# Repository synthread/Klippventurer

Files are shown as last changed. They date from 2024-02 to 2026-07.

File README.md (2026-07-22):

<div align="center">
  Klippventurer logo
  <h1>Klippventurer</h1>
  <h3>Klipperize your FlashForge printer!</h3>
  <a href="https://discord.gg/ns2pFdhdMW">
    
    
  </a>
</div>

<div align="center">
  <a href="#compatibility">Compatibility</a> •
  <a href="#installation">Installation</a> •
  <a href="#known-issues">Known Issues</a> •
  <a href="docs/changelog.md">Changelog</a> •
  <a href="#special-thanks">Special Thanks</a>
</div>

> [!IMPORTANT]
> `main` documents the current live Klippventurer setup: a **v0.2.x manual/soldered host install** workflow (ongoing state, not a tagged release line).
> Looking for the next-generation stock-like USB installer work? See the preview **USB Install Branch**: [`next/firmware-package`](https://gitlab.com/synthread/proj/Klippventurer/-/tree/next/firmware-package).
> That branch is preview-only and is not merged to `main` until a verified USB installer exists.

## Compatibility

|Printer|Printing|Easy Installer|Pin table|Printer.cfg|Thermistor Calibration|Display|Touch|Filament Runout|Camera|
|---|---|---|---|---|---|---|---|---|---|
|Adventurer 3/Pro*|✅|⏰|✅|✅|⏰|⏰|⏰|⏰|⏰|
|Adventurer 3 Pro 2|❓|⏰|❓|❓|⏰|⚠️|⚠️|⚠️|⚠️|
|Adventurer 4|⚠️|⏰|⚠️|⚠️|⏰|⚠️|⚠️|⚠️|⚠️|
|Adventurer 5M/Pro|✅|⚠️|✅|✅|✅|✅|✅|✅|✅|
|Creator Pro 2|⚠️|⚠️|❓|⚠️|⚠️|⚠️|⚠️|❌|❌|
|Creator 3/Pro |⚠️|⏰|⚠️|⚠️|⚠️|⚠️|⚠️|❌|❌|

✅Working ⠀⠀ ⏰In Progress ⠀⠀ ⚠️Not yet Working ⠀⠀ ❌Not planned or lacks hardware feature ⠀⠀ ❓Untested, might work

> [!NOTE]
> "Adventurer 3" Includes the Adventurer 3C, Lite, and Pro, as well as rebrands such as the Bresser Rex, Arçelik PT1000, MonoPrice Voxel, and potentially other printers based on the SZ16 mainboard.

## Installation
For installation instructions, please see [the docs](docs/installation.md)

> [!WARNING]
> Always calibrate your Z offset and mesh bed leveling after installing Klipper!

This repo, supported features, and guides change often, join our [Discord](https://discord.gg/ns2pFdhdMW) or watch the repo for updates.
Please open an issue or pull request if you encounter any problems with installation.

## Known Issues 
### Adventurer 3 Models
- Nation N32G MCU doesn't work with current .config
- Can't currently support screen, buzzer, USB, filament runout sensor, or camera. Support for these is planned as part of future USB installer work.
- Adventurer 3 Pro works, but you need to modify printer.cfg to use TMC2209 drivers instead of TMC2208.

## Special Thanks
[@hw-lunemann](https://github.com/hw-lunemann) for fixing UART muxing and tuning input shaper on Adventurer 3

[@kyleisah](https://github.com/kyleisah) and everyone who contributed to [KAMP](https://github.com/kyleisah/Klipper-Adaptive-Meshing-Purging)

[@KevinOConnor](https://github.com/KevinOConnor) and everyone who contributed to [Klipper](https://github.com/Klipper3d/klipper)

[@FlashforgeOfficial](https://github.com/FlashforgeOfficial) for good hardware at a fair price

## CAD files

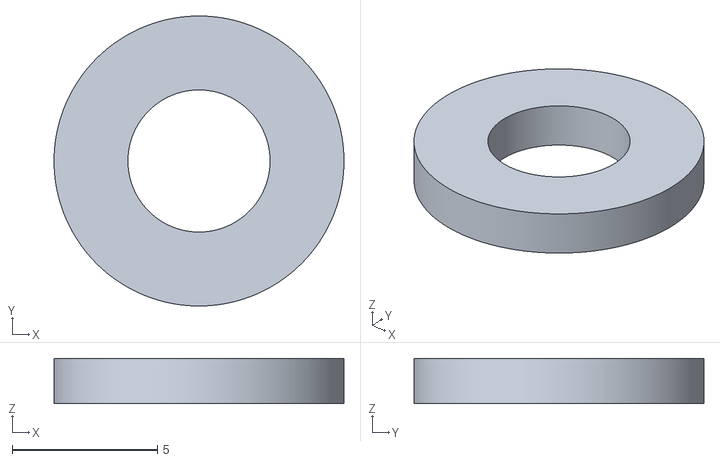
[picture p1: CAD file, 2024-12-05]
STLs/Adv3 Extruder Spacer.stl
10.00 x 10.00 x 1.56

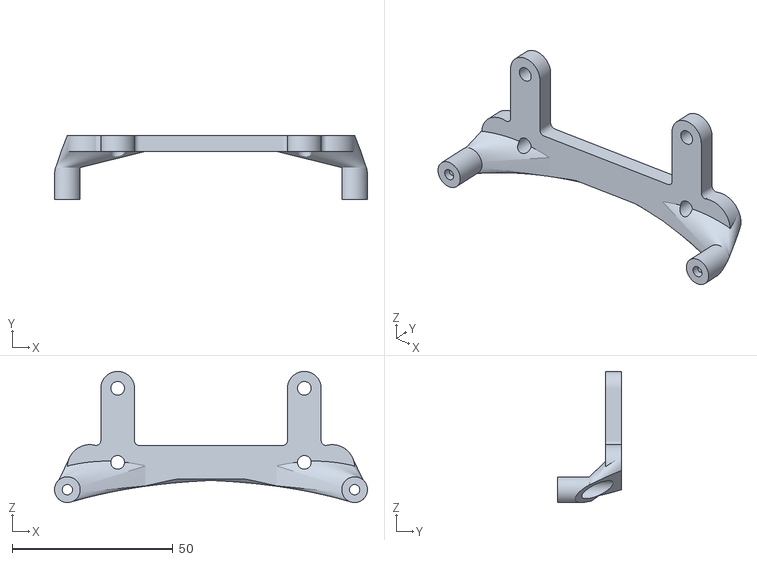
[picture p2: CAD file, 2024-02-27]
STLs/Adv3 Pi Zero mount.stl
97.2 x 20.0 x 40.7

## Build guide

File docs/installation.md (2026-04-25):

# Installation ADV3

> [!CAUTION]
> You should be familiar with installing and configuring Klipper before attempting this.
> You are solely responsible for any damage caused by following any part of this guide.

> [!WARNING]
> This guide will soon be deprecated as this install method is considered to be in an ALPHA testing state.
> Public testing for the BETA install method will be beginning soon, join our Discord to keep up to date with announcements.

> [!WARNING]
> CHECK your microcontroller brand before attempting this. It will only work on STM32, HK32, and GD32 MCUs.
> Nation N32 MCUs are not supported by this guide as they need to be programmed via a slightly different method.

> [!NOTE]
> This Guide was written with [Raspberry Pi Imager v2.0.2](https://github.com/raspberrypi/rpi-imager/releases/tag/v2.0.2) and Raspbian GNU/Linux 12 (bookworm) armv7l on a [Raspberry Pi Zero 2 W Rev 1.0](https://www.raspberrypi.com/products/raspberry-pi-zero-2-w/) with Linux 6.12.47+rpt-rpi-v7

## Requirements

+ very basic soldering skills
+ a soldering iron with temperature control
+ solder (preferably SnPb or SnBi solder, SnAg is harder to work with)
+ A [Raspberry Pi Zero 2 W](https://www.raspberrypi.com/products/raspberry-pi-zero-2-w/) (or any other Pi you'll just need to select it in the Raspberry Pi Imager)
+ SD card (at least 4GB, 16GB or larger recommended)
+ insulated silicone wire, multiple colors preferred (silicone insulation won't melt during soldering)
+ 4x M2.5x4 screws
+ 4x M2.5 threaded heat-set inserts
+ Raspberry Pi Zero mount from the [STLs](/STLs/) folder

### Recommended

+ Extruder tensioning spacer from the [STLs](/STLs/) folder
+ paste or liquid flux
+ cotton swabs and or cotton pads (something to clean the board with)
+ IPA or PCB cleaner

## Part 1 - Get Connected 🔌

> [!IMPORTANT]
> Don't work inside the printer with the power cable connected

Step 1: Print the Pi mount and (optional) extruder spacer from the [STLs](/STLs/) folder. The Pi mount is designed to be printable on Adventurer 3 without support material. PLA may not work due to the temperature of the electronics enclosure, HTPLA or higher glass transition filament (PETG, ABS, etc.) recommended.
Insert the 4 threaded inserts into the Pi mount using your soldering iron with a conical tip or threaded insert tip.

Optional Step: With the printer unplugged, use a hex 2.5 bit or Allen key to remove the tensioning arm from the extruder assembly behind the filament hatch. Be careful not to drop the spring into the housing of the printer, it's much less work if you don't have to fish the spring out. Install the spacer onto the spring retention peg. Reassemble the extruder. Video demonstration here: https://www.youtube.com/shorts/PZRefwOkk9g
This will improve the maximum flow rate significantly, and coupled with the increased extruder motor torque in Klipper, massively reduces or eliminates the clicking extruder issue.

Step 2: Unplug your printer. Carefully turn the printer upside down on a soft surface so as to not scratch the top acrylic panel.
Remove the 4 screws securing the metal electronics cover.
You may choose to remove the board from the printer and place it on your work surface to make soldering easier.
If you do, you'll need to remove the glue covering the MHF micro-coax Wi-Fi antenna cable, unplug all connectors, and remove all 4 screws securing the board.

Step 3: Locate the pads in the diagram ([Wiring-diagram.png](../images/adv3-diagram.png)), apply flux, then tin the pads.

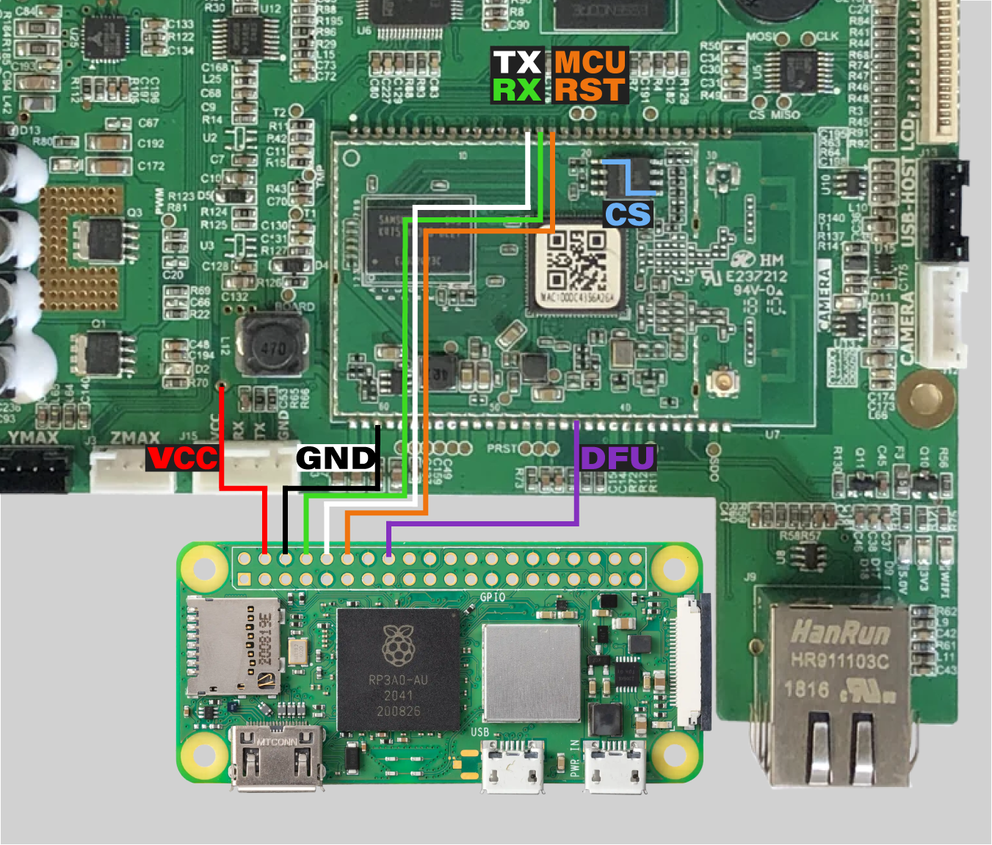
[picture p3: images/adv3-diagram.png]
wiring diagram


Step 4: Solder your wires to the pads as indicated. Make sure all wires are long enough to connect to your Pi, about 10cm or 4in. Strip both ends before soldering to make your life easier later (about 2mm on each end)
You should connect the following to your printer's mainboard:
+ one wire to TX (white)
+ one wire to RX (green)
+ one wire to MCU RST (orange)
+ one wire to DFU (purple)
+ one wire to VCC (red)
+ one wire to GND (black)
+ bridge CS (blue)

## Part 2 - Prepare The Pi 🪛

Step 1: Download the latest [Raspberry Pi Imager](https://www.raspberrypi.com/software/) Under "Raspberry Pi Device" select "Raspberry Pi Zero 2 W" (or your Pi). For Operating System, go to "Raspberry Pi OS (other)" and select "Raspberry Pi OS (Legacy, 32-bit) Lite", choose your SD card, then hit next. Complete Customisation (like selecting your hostname). Under "Remote Access" enable SSH and select "Use password authentication" (unless you know what you're doing). Save, then click "Write" and "I UNDERSTAND, ERASE AND WRITE" when it asks if you're sure you want to continue. Once done writing the SD, remove it and insert it into the Pi.

Step 2: If you removed the mainboard to solder your wires, reinstall it now, but leave out the 2 screws closest to the power socket. If you left the board in, go ahead and remove those 2 screws now. Place your Pi mounting bracket on the mainboard with the two legs aligned with the holes in the mainboard. Insert the two mainboard screws through the bracket and mainboard to secure them both. Using the 4 M2.5 screws, secure the Pi to the mounting bracket.

Step 3: Time to test! Plug the printer back into power, and flip the switch on. The printer **should not** boot up. Screen should remain black, mainboard LEDs should come on, the Pi should power up, and nothing else should happen. If the printer does boot normally into the stock firmware, make sure the CS bridge is in place and works. If all works, now is the time to clean the flux off the board with your cleaner and cotton swabs.

## Part 3 - Klipper, Mainsail, Fluidd, Orca Slicer! ⛵💧🐋

Step 1: SSH into your Pi. You'll need to find the IP in your router's config page or app.

Run the following commands:

```sh
echo -e "enable_uart=1\ndtoverlay=miniuart-bt\ndtoverlay=disable-bt" | sudo tee -a /boot/firmware/config.txt
sudo sed -i 's/console=serial0,115200 //' /boot/firmware/cmdline.txt
sudo apt update && sudo apt install stm32flash git -y
cd ~ && git clone https://github.com/dw-0/kiauh.git
git clone https://gitlab.com/synthread/3d/Klippventurer.git
./kiauh/kiauh.sh
```

Once at the KIAUH menu, install 1) Klipper, 2) Moonraker, and 4) Fluidd. You can also install Mobileraker (under Extensions) for mobile push notifications via the [Mobileraker app](https://mobileraker.com/).
Exit KIAUH with B then Q and do

```sh
cp -r ~/Klippventurer/config/ ~/printer_data/
wget -O ~/klipper/.config https://gitlab.com/synthread/3d/Klippventurer-Installer/-/raw/main/configs/adventurer3.config
cd ~/klipper && make menuconfig
```

press Q followed by Y. Now

```sh
make
```

and if the build completes without errors,

```sh
sudo reboot
```

Wait for the Pi to reboot, SSH back in and run

```sh
sudo stm32flash -w ~/klipper/out/klipper.bin -R -i -530,535,530:-530,-535,530 /dev/ttyAMA0
```

A successful flash should look something like this:

```sh
stm32flash 0.7

http://stm32flash.sourceforge.net/

Using Parser : Raw BINARY
Size         : 38368
Interface serial_posix: 57600 8E1

GPIO sequence start
 setting gpio 530 to 0... OK
 delay 100000 us
 setting gpio 535 to 1... OK
 delay 100000 us
 setting gpio 530 to 1... OK
GPIO sequence end

Version      : 0x10
Option 1     : 0x00
Option 2     : 0x00
Device ID    : 0x0414 (STM32F10xxx High-density)
- RAM        : Up to 64KiB  (512b reserved by bootloader)
- Flash      : Up to 512KiB (size first sector: 2x2048)
- Option RAM : 16b
- System RAM : 2KiB
Write to memory
Erasing memory
Wrote address 0x080095e0 (100.00%) Done.

Resetting device...

GPIO sequence start
 setting gpio 530 to 0... OK
 delay 100000 us
 setting gpio 535 to 0... OK
 delay 100000 us
 setting gpio 530 to 1... OK
GPIO sequence end

Reset done.
```

You should now be able to access the Fluidd interface from your browser or Orca Slicer. If you don't get an error (warnings are fine), go ahead and unplug the printer and reinstall the bottom cover. You may need to try restarting the firmware.

Set it back right-side-up and power it on. Reconnect to Fluidd, cross your fingers, and hit the home button!

Calibrate your Z offset and make a bed mesh and also probably an [PID calibration](https://www.klipper3d.org/Config_checks.html#calibrate-pid-settings)!

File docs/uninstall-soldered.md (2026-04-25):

# Uninstall (soldered)

Reverting your printer to stock firmware is easy. Simply remove your wires from the mainboard, remove the Pi mount, and power on the printer. After a short wait on the splash screen, you should be greeted by a prompt asking if you want to retry the "update". This will reinstall the factory firmware on the microcontroller. Follow the on-screen prompts and your printer should be back to stock in no time. If this is unsuccessful, don't worry, and continue on to the troubleshooting section below.

## Troubleshooting
Sometimes, this built-in recovery mechanism can fail to reinstall the original firmware. In this case, you will need to reinstall the firmware manually. Thankfully, this is easy to do and only requires a USB flash drive. Steps are as follows: 

0) Download the latest firmware for your printer from the manufacturer's website. For the FlashForge branded Adventurer 3, it can be found [here.](https://archive.org/details/adv-3-firmware) For rebrands, you can likely find your firmware on the seller's website by Googling "\<printer name> firmware" or you can try using the official firmware from FlashForge. Some models such as the MonoPrice Voxel can unlock additional features by using official firmware instead of firmware from the printer's distributor.

> [!CAUTION]
> Do not use a flash drive containing any important files, you will need to erase this drive.

1) Insert your USB flash drive into your PC.
2) Flash your drive to FAT32:
    - (Windows) Use [GUIFormat](http://ridgecrop.co.uk/index.htm?guiformat.htm) to format your flash drive as FAT32
    - (Linux) Use your tool of choice to format your flash drive as FAT32
    - (macOS) Open Disk Utility. Select your flash drive on the left, then "Erase". Choose "MS-DOS (FAT32)" from the dropdown, then click the "Erase" button.
3) Extract the firmware .zip file. Open the folder within to find your firmware name e.g. Adventurer3-*.tgz Move this file onto your empty flash drive, and eject it from the computer.
4) With the printer powered off, insert your USB flash drive. Power on the printer.
5) You should see a firmware update begin after the splash screen. Once this is completed, you may remove the flash drive and restart the printer. You should now be back to factory firmware!

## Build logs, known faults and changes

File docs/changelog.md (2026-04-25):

# Changelog

This changelog tracks user-facing changes to the current live Klippventurer project line.

## v0.2.2 - Upcoming

### Changed

- Clarifies that `main` is the current live v0.2.x manual/soldered host install workflow.
- Links from the README to the preview **USB Install Branch** (`next/firmware-package`) for next-generation stock-like USB installer work.
- Centers the README navigation links under the Discord badge for GitLab rendering.
- Updates the Adventurer 3 installation guide for Raspberry Pi Imager 2.0.2 and Raspberry Pi OS Bookworm paths.
- Updates setup commands to use GitLab-hosted Klippventurer URLs.
- Temporarily keeps KAMP setup out of the manual installation flow pending Discord context and a proper fix for the issue that prompted its removal.
- Updates STM32 flashing instructions and includes an example successful `stm32flash` output.
- Adds clearer post-install calibration guidance.
- Updates the soldered-install recovery firmware link.

### Notes

- This remains the manual/soldered host install project line.
- N32 MCU support and the stock-like USB installer are not included in v0.2.2; those are being developed on the preview USB installer branch.

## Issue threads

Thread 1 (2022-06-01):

Support stock mainboard

VioSynthax, 2022-06-01:
Stock mainboard can be supported by running Klipper, Mainsail, and Fluidd off of the original Mediatek MT7688 running a somewhat modified OpenWrt installation. This requires a good understanding of Linux. This could be done in one of three ways.

Method 1 [best method]) Create a USB installer that updates the kernel to the latest (older FlashForge kernel can't run Klipper) and installs KlipperWrt while disabling all of the FlashForge start scripts except the updater script, so that any update USB can revert the printer to stock. Flash the MCU and print away. (best method)

Method 2 [2nd best]) Connect to the MT7688 via serial UART and manually disable FlashForge's start scripts after updating to the latest firmware. Fix the OpenWrt installation and add KlipperWrt's distfeeds. Install KlipperWrt manually, then flash the MCU.

Method 3 [not recommended]) Gain SSH access via CrashForge, then manually install everything the same way as method 2. Harder to unbrick than method 2.

dJOS1475, 2022-06-01:
Howdy, I'd love to change my AD3 over to Klipper (I currently run it on my main printer SKR2 powered and heavily modified Mega Zero v1.0).

Method 1 would be ideal - how close are we to being able to do this?

dJOS1475, 2022-06-01:
Awesome, if you'd like me to test I'm happy to help out. I dont mind risking my unit as it's my "backup" printer and if it goes very badly wrong I'll just have to replace the main board with a Mellow Fly. 🤣

VioSynthax, 2022-06-01:
> Awesome, if you'd like me to test I'm happy to help out. I dont mind risking my unit as it's my "backup" printer and if it goes very badly wrong I'll just have to replace the main board with a Mellow Fly. 🤣

I originally was just going to throw in a new board entirely but felt bad at wasting good TMC2209s 😋

dJOS1475, 2022-06-01:
PS. I was planning to make an adapter PCB board to allow the easy swap in of a RepRap Fly board - unfortunately I just havent had the time to map out the FlatFlex pinouts etc

VioSynthax, 2022-06-04:
> PS. I was planning to make an adapter PCB board to allow the easy swap in of a RepRap Fly board - unfortunately I just havent had the time to map out the FlatFlex pinouts etc

I've mostly mapped out the flex, but not entirely. I didn't spend enough time on it to figure out how the LED is connected, but now that I have it running Klipper it'd be easy enough to just enable things one-by-one and measure which pin has voltage. I think making some adapter boards and firmware mods for these printers would really breathe a lot of life into quite a few machines that would otherwise become e-waste.

dJOS1475, 2022-06-04:
Agreed, mine just doesn’t get used ATM due to the horribly inaccurate bed leveling. I’m hoping Klipper will solve that issue as the “paper test” in Klipper had much more precise z axis control than the Flashforge firmware.

Btw I bought a PEI spring steel bed for it mine which would be awesome for printing ABS+ if I could get the bed mesh sorted.

https://a.aliexpress.com/_mM14t4W

VioSynthax, 2022-06-04:
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

Yeah, without a probe it's still not as good as I'd like it, but maybe that's just me. My theory is that it's somewhat due to backlash, but I believe Klipper's manual leveling "bounces" between moves to prevent inaccuracies caused by backlash. I got mine pretty good and then edited the mesh by hand doing a few first layer tests until it was nearly perfect across the entire bed.
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

dJOS1475, 2022-06-05:
Wow, that’s massively better than what I’ve been getting out of mine!

Borillion, 2022-11-14:
Sorry to bump this if its necro/abandoned. I have one of these that I was able to get SSH access into using a reverse shell, by pulling and modding the scripts off of a usb firmware update.

I assume I have to start by pulling the device tree and kernel configuration off after updating to the newest firmware.

Not too familiar with building openwrt willing to give it a good try but will need someone to discuss the process with.

When printing it seems to write to some /sys/kernel/ pinctrl devices. So far i'm just poking dangerously and playing with strace/ptrace and the qtlib qui.

VioSynthax, 2023-01-09:
> I have got a [Arçelik PT1000](https://www.arcelik.com.tr/3d-yazici/arcelik-3d-yazici-pt1000-3d-yazici) last week thinking that it is another rebrand of the Adventurer 3 but suprisingly enough it has some differences like a newer revision of the main board and a different heat plate (looks like Adventurer 4 bed but smaller). Most importantly it has OpenWRT 18.06.4 installed with the 4.14.131 kernel and i cannot install the official firmware because of that. I can share the whole disk image in exchange of a disk image from the official model so i can install the flashforge software and you can try to install the KlipperWRT on 4.14.131 kernel.

Can you share a high resolution clear photo of the mainboard? If the hardware isn't supported by FF's firmware it won't work even if you get it to install. It probably won't install Adventurer firmware because their update mechanism either works differently or checks the update USB before applying it. If you can get Crashforge to run on it, it should be quite easy to force install the Adventurer firmware. Why do you want Flashforge's firmware anyway, does it have features the stock firmware doesn't?

VioSynthax, 2023-01-09:
Probably doesn't have a camera to free up the USB header for the RFID reader. If you want to flash a different kernel, your best bet is to either use a SOIC clip on the NOR flash on the Mediatek board, or flash it by accessing U-boot's boot menu via serial, if the boot menu is enabled on the bootloader they are using.

hw-lunemann, 2024-01-07:
Hey I'm back! Sorry for not getting back to this or updating on my progress.
I have long given up on getting klipper to run on the embedded mediatek board and haven't really worked on it anymore either. It simply doesn't have enough ram to make it fit. That would definitely been nice though but even if it did fit, the CPU is also very slow and could have supported tectnoically slow printing speeds.

Good news is that I started work on figuring out how to flash the STM32 without connecting a Pi or soldering, and I'm happy to report that I have been successful! This method doesn't need anything but a computer and an USB stick.  The only problem is that I have modified the OS on the printer significantly along the way and the "stock" backup I had from earlier this year isn't exactly stock either. So it would be tremendously helpful if one of you guys could share a stock dump of the 8gb eMMC that contains the OS so I can make this reproducible for anyone.
```
root@FlashForge:~# stm32flash /dev/ttyS1
stm32flash 0.4

http://stm32flash.googlecode.com/
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
brendann993, 2024-01-13:
If I'm reading this right, is the two ideas for solderless Klipper to create the debug port to MCU UART bridge on the existing board (probably as part of a modified upgrade script?) and then run Klipper on the raspberry PI connected to the debug port?
Or in the case of @hw-lunemann way, being similar but doing the bridge over ethernet rather than the debug port.

hw-lunemann, 2024-01-14:
@brendann993 Correct! I have been printing with my setup for a few days now and forwarding the firmware and host communication over the network hasn't failed a single time. It's outstandingly reliable for me. I've also overhauled the config that's found in this repository to fix a few outstanding issues and to make improvements. Stay tuned!

VioSynthax, 2024-01-14:
> If I'm reading this right, is the two ideas for solderless Klipper to create the debug port to MCU UART bridge on the existing board (probably as part of a modified upgrade script?) and then run Klipper on the raspberry PI connected to the debug port? Or in the case of @hw-lunemann way, being similar but doing the bridge over ethernet rather than the debug port.

There are a few options. The printer can be upgraded with a Pi to boost processing power by either installing it internally, connected to the debug serial interface, or the UART between the microcontroller and the main processor can be forwarded over ethernet to the Pi for an external install. The third option is to forego the Pi and only use the existing hardware, but we currently don't know if there's enough RAM for Klipper and enough processing power for input shaper and pressure advance even if there is enough RAM. If it does work, it will be a very tight fit.

Also, I've seen the progress @hw-lunemann has made on configuration and tuning, the machine is printing even better than I could have hoped 😁

VioSynthax, 2024-02-27:
Time for a quick update. There's not enough RAM for Klipper. The fact that it uses Python and compiles some C modules at runtime is just too much for the 64MB we have to work with. Good news though! Klipper is pretty much tuned, I've designed an internal Pi mount for a Zero 2 W, and I have an Orca Slicer profile that works **really** well with the models and filaments I've tried so far. I also made a simple little spacer for increasing the extruder tension, which paired with the torque boost we can get by increasing motor current really uncorks this printer. I've been printing at 0.2mm layer height and getting good quality prints at about 7.5mm<sup>3</sup>/s flow rate, 4000mm/s<sup>2</sup> print acceleration and travel speeds of up to 900mm/s with 5000mm/s<sup>2</sup> accel. (I slowed down to 750mm/s to improve noise quality)

In other news, the project will be re-released this week with v2 of the install guide! I'll upload some demo videos of what kind of speeds and quality you can expect with a stock machine, and begin work on some physical upgrades to boost performance even further (This thing is **FAST!** the extruder and hotend hold it back **massively**. Direct drive conversion, anyone?) Before I go too far into the speed rabbit-hole though, I'd like to flesh out the installation methods and work on feature support.

Given that this Issue is about unmodified mainboards, I'll explain a little bit about the plan for that install method. The good news is, it's possible! And, we have a plan for making it happen. The bad news is that it won't be making the cut for v2 of the guide. My 2023 was insanely busy. I moved to a new continent, and for a few months there I didn't even own an Adventurer 3 anymore. Now that I'm back though, I feel that it's time to get the project into other people's hands and get some real testing under way. v3 of the guide will have at least 2 different install methods, and should include full feature parity with the stock firmware. Currently the piezo buzzer, filament runout sensor, screen, USB port, and camera aren't working as those are all handled by the original Linux system onboard the Adventurer 3. @threadproc and I are working on a solution that will allow us to use those features by forwarding the necessary data from the onboard computer to the Pi, even on a bone-stock machine. you won't have to disassemble the machine or even open the bottom panel. Just insert the USB installer, plug your Pi into the ethernet port, and you have a Klipperized Adventurer 3 (or MonoPrice Voxel, or Arçelik PT1000, or ...)

VioSynthax, 2024-02-27:
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

Now that I own an Adventurer 3 again, I was able to make a dump of the eMMC. Do you still need it?

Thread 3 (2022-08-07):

Full Klipper ROM config?

dJOS1475, 2022-08-07:
Howdy, I finally got around to removing the old MIPS MCU (good riddance) and have successfully flashed STM32Duino.bin and my own klipper.bin to the specified ROM locations. However, I'm not getting a successful startup. Can you please confirm the full Klipper Firmware Configuration options please?

                         Klipper Firmware Configuration
[*] Enable extra low-level configuration options
    Micro-controller Architecture (STMicroelectronics STM32)  --->
    Processor model (STM32F103)  --->
[ ] Only 10KiB of RAM (for rare stm32f103x6 variant)
[ ] Disable SWD at startup (for GigaDevice stm32f103 clones)
    Bootloader offset (28KiB bootloader)  --->
    Clock Reference (12 MHz crystal)  --->
    Communication interface (Serial (on USART1 PA10/PA9))  --->
(250000) Baud rate for serial port
()  GPIO pins to set at micro-controller startup

VioSynthax, 2022-08-07:
Hello,

Try using the included Klipper bin for your initial setup to make sure everything else in your setup is working and your MCU is able to be communicated with from your CPU (Pi or otherwise). If Klipper needs the MCU (STM32 or clone) to be updated, then go ahead and compile the newer controller firmware for it. Those options don’t look right, but it’s been a while so I’ll need to take a look at the files and see what the config should be.

dJOS1475, 2022-08-07:
no worries, It's always nice to know the settings just in case you need to recompile (happens sometimes with klipper updates)

dJOS1475, 2022-08-07:
Hmm, even with your FW I just get what sounds like a boot loop with lots of clicking noises from the little speaker. Do I need the DFU jumper connected for the klipper.bin? I had it there for the stm32 bin and STM32 cube programmer has been reporting successful programs. eg

   21:31:50 : ST-LINK SN  : 490046000100004D32414D4E
  21:31:50 : ST-LINK FW  : V2J29S7
  21:31:50 : Board       : --
  21:31:50 : Voltage     : 3.19V
  21:31:50 : SWD freq    : 4000 KHz
  21:31:50 : Connect mode: Normal
  21:31:50 : Reset mode  : Software reset
  21:31:50 : Device ID   : 0x414
  21:31:50 : Revision ID : --
  21:31:50 : Debug in Low Power mode is not supported for this device.
  21:31:50 : UPLOADING OPTION BYTES DATA ...
  21:31:50 :   Bank          : 0x00
  21:31:50 :   Address       : 0x4002201c
  21:31:50 :   Size          : 8 Bytes
  21:31:50 :   Bank          : 0x01
  21:31:50 :   Address       : 0x1ffff800
  21:31:50 :   Size          : 16 Bytes
  21:31:50 : UPLOADING ...
  21:31:50 :   Size          : 1024 Bytes
  21:31:50 :   Address       : 0x8000000
  21:31:50 : Read progress:
  21:31:50 : Data read successfully
  21:31:50 : Time elapsed during the read operation is: 00:00:00.006
  21:31:53 : Memory Programming ...
  21:31:53 : Opening and parsing file: klipper.bin
  21:31:53 :   File          : klipper.bin
  21:31:53 :   Size          : 21.06 KB
  21:31:53 :   Address       : 0x08002000
  21:31:53 : Erasing memory corresponding to segment 0:
  21:31:53 : Erasing internal memory sectors [4 14]
  21:31:54 : Download in Progress:
  21:31:55 : File download complete
  21:31:55 : Time elapsed during download operation: 00:00:01.757
  21:31:55 : Verifying ...
  21:31:55 : Read progress:
  21:31:55 : Download verified successfully
  21:32:02 : Disconnected from device.

VioSynthax, 2022-08-07:
> Hmm, even with your FW I just get what sounds like a boot loop with lots of clicking noises from the little speaker. Do I need the DFU jumper connected for the klipper.bin? I had it there for the stm32 bin and STM32 cube programmer has been reporting successful programs. eg
>
> 21:31:50 : ST-LINK SN : 490046000100004D32414D4E 21:31:50 : ST-LINK FW : V2J29S7 21:31:50 : Board : -- 21:31:50 : Voltage : 3.19V 21:31:50 : SWD freq : 4000 KHz 21:31:50 : Connect mode: Normal 21:31:50 : Reset mode : Software reset 21:31:50 : Device ID : 0x414 21:31:50 : Revision ID : -- 21:31:50 : Debug in Low Power mode is not supported for this device. 21:31:50 : UPLOADING OPTION BYTES DATA ... 21:31:50 : Bank : 0x00 21:31:50 : Address : 0x4002201c 21:31:50 : Size : 8 Bytes 21:31:50 : Bank : 0x01 21:31:50 : Address : 0x1ffff800 21:31:50 : Size : 16 Bytes 21:31:50 : UPLOADING ... 21:31:50 : Size : 1024 Bytes 21:31:50 : Address : 0x8000000 21:31:50 : Read progress: 21:31:50 : Data read successfully 21:31:50 : Time elapsed during the read operation is: 00:00:00.006 21:31:53 : Memory Programming ... 21:31:53 : Opening and parsing file: klipper.bin 21:31:53 : File : klipper.bin 21:31:53 : Size : 21.06 KB 21:31:53 : Address : 0x08002000 21:31:53 : Erasing memory corresponding to segment 0: 21:31:53 : Erasing internal memory sectors [4 14] 21:31:54 : Download in Progress: 21:31:55 : File download complete 21:31:55 : Time elapsed during download operation: 00:00:01.757 21:31:55 : Verifying ... 21:31:55 : Read progress: 21:31:55 : Download verified successfully 21:32:02 : Disconnected from device.

Hmm, looks like it might be flashed to the wrong location, there's an extra 0 in the address you're flashing the klipper.bin firmware to. Reflash your bootloader to make sure it's intact at 0x08000000, then flash klipper.bin at 0x8002000. I seem to recall an issue where my STM32 wasn't booting, with the solution being to use these addresses exactly this way. You can also see what error you're getting stopping it from booting by using the fault analyzer in CubeProg. As far as I can tell, both the STM32 used on this board and its clones use the 0x08 as their boot address, and the bootloader should be using the 0x8002 as the location it looks to launch firmware from. I'd copy paste those as-is and see if anything changes.

dJOS1475, 2022-08-07:
Ok, I tried that and went through the whole process again and same result. Do I need the DFU jumper everytime, or was that just to unlock the eeprom the first time?

Here are my programmer settings just in case im doing something wrong (klipper.bin):
https://imgur.com/a/tu92wnX

VioSynthax, 2022-08-07:
> Ok, I tried that and went through the whole process again and same result. Do I need the DFU jumper everytime, or was that just to unlock the eeprom the first time?
>
> Here are my programmer settings just in case im doing something wrong (klipper.bin): https://i.imgur.com/fzPtGNJ.jpg

Set to skip erase before flashing or you'll erase your bootloader while writing klipper. Also, I think your start address on the CPU page needs to remain 0x08000000 so it knows where the bootloader's first instruction is, but you'll need to set the flash address to 0x8002000 while flashing klipper. Been a while since I've had time to work on my printer, but I'll try to make sure you get yours up and running. Iirc you'll need to jump the DFU pins on startup, then flash bootloader (and not checking boot after flashing, make sure you aren't wiping the flash while you program firmware to the 2nd address. Then you can power off and see if it's being detected over the Pi's serial port (are you using a Pi? Which one? There's a process to set up the serial port on them so it doesn't get reserved for the Bluetooth module, for the Pis that have one)

VioSynthax, 2022-08-07:
My Discord is Synthax#0001 if you want some more real-time assistance, just remind me to post or post the solution yourself here so I can close the issue :)

dJOS1475, 2022-08-07:
Cheers, Im a noob when it comes to STM32 flashing. If I skip flash erase, it fails to download file. However when I tried this it worked:

https://i.imgur.com/pOsXdWY.jpg

but I still get the boot loop and clicking. Anyway dude, thanks for the help so far, Im off to bed. I'll have another swing at it tomorrow.

dJOS1475, 2022-08-07:
btw, Im using a Pi3A with Mainsail installed via the custom image from github

dJOS1475, 2022-08-08:
Argh, I can program the STM32 to my hearts content, and can read back both address locations without issue and compare between programmed and erased. But I can just cant connect to the dam thing from my Pi.

I solved the clicking / reboot issue - that was my fault. I got my serial wires mixed up and had GND and TX flipped. 🤦‍♂️

dJOS1475, 2022-08-08:
Hmmm, after a bit more digging, I have "GD32F103 RCT6" with 10KiB of RAM and 256KiB of Flash made by GigaDevice. Im wondering if that is why it wont play nice?

https://gd32mcu.com/data/documents/datasheet/GD32F103xx_Datasheet_Rev2.12.pdf

dJOS1475, 2022-08-08:
So I tried a different Pi3B with no change. I also tried changing the UART pins when compiling the Klipper binary and I got an leg to turn on in the heater section of the board.

I’ve also been able to confirm that the flash is being written currently by doing a file to rom compare in the STM32 tool. So that confirms that side of things is good.

i still can’t connect to the blasted UART port tho and I’m wondering if you have a real STM32 on your board? Mine is the GD32 which I’ve found info suggesting it isn’t 100% identical to the real thing.

dJOS1475, 2022-08-09:
Ok, I've tried connecting to the board with Pronterface via serial and I cant get it to respond either - I may have killed the serial interface. :-( But it's be great If you can confirm which STM32 you have?

I've tried your Klipper ROM and also a made ROM's using every UART option with now result.

VioSynthax, 2023-03-14:
Version 2.0 of the guide improves the process and eliminates these issues. Should be pretty straightforward now!

VioSynthax, 2023-03-14:
Still in the 2.0-preview branch as the software setup part instructions and script aren't ready, but it's not too complicated. Gotta enable your UART port and disable bluetooth on the Pi, run KIAUH, copyprinter.cfg where Klipper wants it (can use Fluidd or Mainsail for that), and `make` klipper.bin from ~/klipper with my .config here: https://github.com/VioSynthax/Klippventurer-Installer/blob/main/configs/adventurer3.config

then do `sudo apt install stm32flash` followed by `sudo stm32flash -w ~/klipper.bin -R -i -18,23,18:-18,-23,18 /dev/ttyAMA0`
Keep in mind that command will only work if the Pi is connected as it is in v2 of the guide- https://github.com/VioSynthax/Klippventurer/tree/2.0-preview

Closed 2023-03-14.

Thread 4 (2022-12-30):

E and Z axis TMC config issue

VioSynthax, 2022-12-30:
For some reason, stepper drivers for E and Z aren't responding appropriately to serial commands. The result of this is no response to setting changes such as microstepping, motor current, stealthchop, spread cycle, etc. In practical terms, this means that the extruder has a lack of torque (causing the infamous "clicking" extruder these printers are known for) and both E and Z steppers run hotter than normal. I don't currently know if this is a hardware issue, or if this problem effects a stock printer. If so, this would explain the extruder skipping steps that the Voxel and Adventurer are plagued with.

TODO: probe serial trace to determine where my serial packets are getting lost. Is the muxing wrong? There should be a serial communications error if there's no communication at all, and changing pin muxing does indeed trigger this error, so it at least thinks it's communicating with the drivers. Enabling UART address throws an error, for some reason. More testing required.

VioSynthax, 2024-02-28:
Fixed in 14ffa24

Closed 2024-02-28.

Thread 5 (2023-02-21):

TMC2208's?

ldw300, 2023-02-21:
Is it a problem that the part number on the driver chips of my mainboard is TMC2208-LA? The config and README says TMC2209's. I have an adventurer 3 pro. Seems to be the same mainboard as in the picture.

VioSynthax, 2023-02-21:
> Is it a problem that the part number on the driver chips of my mainboard is TMC2208-LA? The config and README says TMC2209's. I have an adventurer 3 pro. Seems to be the same mainboard as in the picture.

Simple to switch the driver version, just changing all instances of 2209 in config to 2208. You can do a "replace all" for 2209>2208. If you go for it, please report back about your results and any issues you run into along the way! Happy to help in any way I'm able.

ldw300, 2023-02-24:
Gotcha, I'm also having issues connecting to the board to flash it, I have the mediatek chip off and jumper wires soldered in place, but I've tried a usb to ttl and an ftdi cable to connect and i just get ERROR: Activating Device KO from the cube programmer. I can open a seperate issue if needed.

VioSynthax, 2023-02-24:
You may have to use an ST-Link (or clone) like this one https://www.amazon.com/gp/product/B07SQV6VLZ

ldw300, 2023-02-26:
I looked at the clone but was unsure about them. I haven't had good luck with serial communication on other projects as is. So I just ordered the ST-Link v2 from amazon. Little pricey but I think it should work for other future projects.

VioSynthax, 2023-03-15:
ST-Link is no longer required, the new guide uses the Pi to do the flashing and even automates the DFU and reset process. You can return that ST-Link V2 and get your $60 back :)

ldw300, 2023-03-15:
Sounds great!

VioSynthax, 2024-02-28:
TMC 2208 is now the default config. Adventurer 3 Pro will have a separate config for TMC 2209.

Closed 2024-02-28.

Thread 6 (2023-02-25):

Install without removing MediaTek board

VioSynthax, 2023-02-25:
It should be possible to, in lieu of removing the entire daughter board assembly, prevent it from booting by soldering a jumper between its reset pin and ground, or by bridging its oscillator to ground. Then the normal jumper wires mentioned in the guide can be soldered with the MT CPU board still in place, fully disabling and bypassing it in a way that allows for the printer to be returned to stock unmodified by just removing the jumpers and installing the FF Finder firmware back onto the STM32.

Please reply below if you are interested in trying this method, I'll create a branch soon with the simplified instructions once one or more people show interest.

j-collom, 2023-02-25:
I'm very interested in this, can you please send more information?

ldw300, 2023-02-26:
I am interested, I could not get my UART serial cables to connect so I resoldered the mediatek chip back onto the mainboard and am using the printer now. At least I was waiting for the st-link I ordered to come in before trying again.

VioSynthax, 2023-02-26:
Working on new instructions that should allow this to work, only thing remaining to do is locate the reset point on the daughter board.

VioSynthax, 2023-03-11:
Alright, update time. I've soldered the MediaTek module "MT" back onto the mainboard. I'm going to completely clear my STM32 memory and start over, so I can try to reproduce the issue people are having with getting the bootloader to jump to the firmware. I've made some many changes to the guide (currently not in the main branch) that should help someone new to modding accomplish this mod! I have some new features planned as well, I hope with my loaded schedule I have time to implement them, they'd really make this printer into a really solid machine.

**I need some community help here**- could one of you hook up your STLink to their stock board and use CubeProg to read the contents of their flash and send it to me? (dropdown arrow beside "Read" > Save As ...) I'm hoping to add a "revert to stock" option, which along with the MT disable mod in lieu of a full MT delete should officially make this what you could call a "no cut" mod!

penz6, 2023-04-24:
I am also very interested in it, have an Adventurer 3 that would be awesome with klipper, not very proficient in soldering but feel confident with the software portion.

hw-lunemann, 2023-04-29:
I am currently working on porting latest OpenWRT onto the adv3 mainboard.
```
BusyBox v1.36.0 (2023-04-29 10:58:48 UTC) built-in shell (ash)

  _______                     ________        __
 |       |.-----.-----.-----.|  |  |  |.----.|  |_
 |   -   ||  _  |  -__|     ||  |  |  ||   _||   _|
 |_______||   __|_____|__|__||________||__|  |____|
          |__| W I R E L E S S   F R E E D O M
 -----------------------------------------------------
 OpenWrt SNAPSHOT, r22665-626c84340d
 -----------------------------------------------------
=== WARNING! =====================================
There is no root password defined on this device!
Use the "passwd" command to set up a new password
in order to prevent unauthorized SSH logins.
--------------------------------------------------
root@OpenWrt:~# uname -a
Linux OpenWrt 5.15.108 #0 Sat Apr 29 10:58:48 2023 mips GNU/Linux
```

As far as I can tell so far all of the hardware should be working already.
What's left is figuring out the logistics of getting this installed easily.
Rooting the device is quite simple since the firmware updates run unprotected bash scripts as root and
from there it's going to be possible to install my port of OpenWRT.  With the way flashforge set up the Linux
install it should even easily be possible to install it side by side with the original operating system.

With that setup it should also not be too hard to port the Klipper host software onto the machine and eliminate the need for a raspberry pi entirely. Flashing and communicating with the stm32 daughterboard can be done over UART (ttyS1).

Also both the screen and the touchscreen are controlled over spi so we could even get that functionality back but with Klipper!

Bonus points: This can all be delivered by hijacking the firmware update process of the adv3 by simply plugging in a USB.

VioSynthax, 2023-04-29:
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

This was my original plan, but I didn't have the time to get it fully working at the time. I'd be happy to collaborate on this if you'd like. I ultimately came to the conclusion that it's just too many wires to solder for *full* functionality with a hardmod, and no one would want to solder such a huge bundle of mod wires, though I did get the screen to partially init using the Pi.

hw-lunemann, 2023-04-29:
If you keep working on the stm32 side of things (I'm not sure what/if anything still needs to be done) then I can take care of the Linux side of things.
Have you had to deal with the uboot setup on the adv3 yet?

VioSynthax, 2023-04-29:
> If you keep working on the stm32 side of things (I'm not sure what/if anything still needs to be done) then I can take care of the Linux side of things. Have you had to deal with the uboot setup on the adv3 yet?

Yes, I ultimately replaced it with a build of U-boot with network recovery https://github.com/widora/u-boot-mt7688

hw-lunemann, 2023-04-29:
Oh the installed version already has that.
I load my image into memory with `tftpboot` already.

Does the widora u-boot work without modifications?
Getting that installed would make it even easier to have both Linux installs in parallel.

ldw300, 2023-04-29:
Wasn't there a similar project like this before? I remember seeing someone on Reddit, maybe on GitHub; that hijacked the firmware update process and flashed a normal Linux install.

Either way, that sounds like a much cleaner way of doing things. If my main board usb actually worked, (which I'm pretty sure I fried the main board or the Mediatek board when I was poking around too much) I would definitely be interested in helping testing more.

I might get another main board if I find one for a decent price. But right now I'm looking at building an interface board to accept the ribbon cables and use an SKR pick I have to control everything.

VioSynthax, 2023-04-29:
> Oh the installed version already has that. I load my image into memory with `tftpboot` already.
>
> Does the widora u-boot work without modifications? Getting that installed would make it even easier to have both Linux installs in parallel.

Yeah, but the built in one had fewer features, I believe it's older, and it doesn't have the nice web interface for kernel flashing. From what I remember it works just fine without modification, but I think it had the wrong LED pin set, might be some other minor things but it was plenty for booting, web interface, and UART console

VioSynthax, 2023-04-29:
> Oh the installed version already has that. I load my image into memory with `tftpboot` already.
>
> Does the widora u-boot work without modifications? Getting that installed would make it even easier to have both Linux installs in parallel.
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
VioSynthax, 2023-04-29:
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

Good idea. I noticed it complained about corruption absolutely constantly, I figured it was either just mine or they were prone to it. Is it actually a bad master image on the eMMC?

hw-lunemann, 2023-04-29:
Yep.

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

Yep. The kernel kernel in the mtd partition is from 2017 iirc, so a year older than the one they ended up actually shipping with their hackjob method.
The worst part is that there's no way for a user to recover from a bricked install since they use the live environment to update the system. They aren't using a squashfs, these are the stock kernel args:
```Kernel command line: console=ttyS0,115200 noinitrd root=/dev/mmcblk0p1 rootfstype=ext4 init=/init rw rootwait console=ttyS0,115200n8```

The 115200 baud in the boot loader and linux during the early0 part of the boot console is also a lie btw. It's more like 119500 probably because they set up their build system with the wrong system clock or something like that.

hw-lunemann, 2023-04-29:
I will try to get this done until the 11.05 since I won't be available for a while after that.

penz6, 2023-05-01:
Happy to help if needed, currently working on implementing Octoprint with the stock firmware using the wireless TCP connection, lacks queuing prints but should be possible to at least monitor the print and camera. But it would be much more preferable to run an alternative firmware. Especially since I don't even want to think about what it's phoning home about :(

hw-lunemann, 2023-05-09:
Are you sure octoprint will run on 64mb of ram and a 580Mhz cpu?

penz6, 2023-05-09:
Yeah, ended up just running octoprint on a raspi and connecting over the network using the limited API that it exposes.

hw-lunemann, 2023-05-09:
I wanted to post an update on my work since I won't be able to work on it for a couple weeks.

1. The screen and touchscreen have drivers now and I managed to set up a framebuffer device file for the screen, so drawing to it should be extremely easy now.
2. The usb mux chip is controlled by a simple GPIO pin and I'm pretty sure auto detection of whether a device is plugged in or not is toggled by another but I just haven't gotten around to testing that one yet.
3. The webcam also has a driver now and should work aswell.

I have a rudimentary install script for my port that also backs up the flash and eMMC so this mod is completely reversible.

There's two things that would be very helpful. Fistly a dump of both the stock eMMC and flash just to make sure everything works without having tinkered with the printer and secondly it would be nice if someone could test the widora uboot to make sure it really does work without problems.

I'll finish it up once I'm back and then we should be pretty much all set!

Swamp-Ig, 2023-07-19:
This level of hacking is a bit above my current skills, but happy to contribute testing on my machine if needed.

jabberjabberjabber, 2023-08-23:
I have an Adventurer 4 (actually a monoprice Voxel Pro flashed to an Adv 4). Is there anything I can do to help with this?

VioSynthax, 2023-12-15:
#1 For replacing stock firmware without hardmods

VioSynthax, 2024-02-27:
> I have an Adventurer 4 (actually a monoprice Voxel Pro flashed to an Adv 4). Is there anything I can do to help with this?

Quite possibly! Adventurer 4 support is on the roadmap, I just want to make sure Adventurer 3 is fully featured and easy to set up before moving my attention fully to the 4. I was considering the 5M as well, but since it has enough RAM for native Klipper, FlashForge went and did it themselves. For initial Adv4 support, we just need to know the pins. for the 3, I just probed around with a multimeter with the board out of the machine to figure out where each trace went, and referenced the STM32 datasheet to find the pin name that corresponds to each component. Those go directly into printer.cfg under the correct section for the component in question.

We also need to know where the main CPU reset pin is so we can get the Linux system out of the way (until I can get open firmware running on it that plays nice with Klipper) and we have to know where the microcontroller's UART pins end up so Klipper and the Pi can communicate. Eventually this will be done through ethernet for those that don't wish to solder.

Adventurer 4 also uses a weird microcontroller. It's very similar to STM32, but unlike most clones, it doesn't directly support STM32 binaries. It seems to be the same MCU as Adventurer 5M/Pro uses, so at the very least the FlashForge fork of Klipper should work on it or be easily modified to. https://github.com/g992/flashforge-ad5m-5mpro-research/issues/8 https://github.com/FlashforgeOfficial/AD5M_Series_Klipper/tree/main

Closed 2024-02-27.

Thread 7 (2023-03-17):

X and Y

sharmzy, 2023-03-17:
X and Y have a 17 tooth pulley 2mm pitch, why 33.33, it will throw dimensions of parts off, update that to 34,  tooth count x pitch as per manual ;) also Z probably will work better at 6.4 its not metric but a 1/4" 4 start so that's 0.063 inch/rev, converted 1.6mm X 4 starts, print some parts that require dimensional accuracy. working on a FF CANBUS 4 filament ERCF, love to see other adv enthusiasts I will be sure to watch your progress, great work.

VioSynthax, 2023-03-17:
> X and Y have a 17 tooth pulley 2mm pitch, why 33.33, it will throw dimensions of parts off, update that to 34, tooth count x pitch as per manual ;) also Z probably will work better at 6.4 its not metric but a 1/4" 4 start so that's 0.063 inch/rev, converted 1.6mm X 4 starts, print some parts that require dimensional accuracy. working on a FF CANBUS 4 filament ERCF, love to see other adv enthusiasts I will be sure to watch your progress, great work.

Hey, thanks for opening an issue on this one. I think when I set that up I just considered it "good enough" based on the test prints I was doing, as I was having some difficulties trying to figure out why the "right" numbers were very dimensionally wrong. (I might have miscounted the number of teeth, oopsie) I think what I ultimately did was multiply my numbers by the scaling factor I measured from my test prints. In other words, the "wrong" way, but what can I say, I came from Marlin 😆

I really appreciate you giving me proper numbers. I'd definitely be interested in seeing your project, it sounds very interesting!

Closed 2024-01-14.

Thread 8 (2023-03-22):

thermistor calibration

VioSynthax, 2023-03-22:
Thermistor doesn't seem to read correct values on the higher end with current settings, may need to pick a different thermistor type for printer.cfg or define a custom thermistor.

ldw300, 2023-04-05:
Any luck on the new method? If there is something I can do to help, I can try. My machine is sitting idle until there's at least a alpha or beta to test on this repo. I am monitoring the preview branch atm.

VioSynthax, 2023-04-05:
> Any luck on the new method? If there is something I can do to help, I can try. My machine is sitting idle until there's at least a alpha or beta to test on this repo. I am monitoring the preview branch atm.

Greetings,
The preview branch is ready for use, but once you get to part 3, you have to do the setup manually. Basically just run KIAUH on your Pi, install Klipper, Moonraker, and Fluidd, and copy the cfg to the correct place (so just a normal Klipper setup procedure) then copy the .config to ~/klipper, run `make menuconfig` then save and exit from menuconfig, followed by running `make`

You have to configure your Pi to free up the UART lines, here are the commands to make that easy:
```
sudo sh -c "echo '# Enable UART port' >> /boot/config.txt"
sudo sh -c "echo 'enable_uart=1' >> /boot/config.txt"
sudo sh -c "echo 'dtoverlay=miniuart-bt' >> /boot/config.txt"
sudo sh -c "echo 'dtoverlay=disable-bt' >> /boot/config.txt"

sudo sed -i 's/console=tty1 //' /boot/cmdline.txt
sudo reboot
```
Once the Pi is back and you can SSH back in, `cd` to `~/klipper` again and run the following command `sudo stm32flash -w ~/klipper.bin -R -i -18,23,18:-18,-23,18 /dev/ttyAMA0` And you should be able to use the printer via the Fluidd web interface immediately after flashing. I'll be here if you need any support! Good luck.

VioSynthax, 2024-02-28:
Thermistor calibration is closer, but filaments still all seem to require 15-20°C higher temps than they should before they print correctly. Will need to calibrate it with an external thermistor.

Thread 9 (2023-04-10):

Klipper.bin

ldw300, 2023-04-10:
> Any luck on the new method? If there is something I can do to help, I can try. My machine is sitting idle until there's at least a alpha or beta to test on this repo. I am monitoring the preview branch atm.

Greetings,
The preview branch is ready for use, but once you get to part 3, follow these steps.

Run KIAUH on your Pi. Install Klipper, Moonraker, and Fluidd, then copy the .cfg from https://github.com/VioSynthax/Klippventurer-Installer/tree/main/configs to the correct place (so just a normal Klipper setup procedure) and copy the .config to ~/klipper. `cd` to ./klipper and run `make menuconfig` then save and exit from menuconfig, now run `make`

You have to configure your Pi to enable the serial line. Here are the commands to make that easy:
```
sudo sh -c "echo '# Enable UART port' >> /boot/config.txt"
sudo sh -c "echo 'enable_uart=1' >> /boot/config.txt"
sudo sh -c "echo 'dtoverlay=miniuart-bt' >> /boot/config.txt"
sudo sh -c "echo 'dtoverlay=disable-bt' >> /boot/config.txt"

sudo sed -i 's/console=tty1 //' /boot/cmdline.txt
sudo reboot
```
Once the Pi is back and you can SSH back in, run the following command `sudo stm32flash -w ~/klipper.bin -R -i -18,23,18:-18,-23,18 /dev/ttyAMA0` And you should be able to use the printer via the Fluidd web interface immediately after flashing. I'll be here if you need any support! Good luck.

_Originally posted by @VioSynthax in https://github.com/VioSynthax/Klippventurer/issues/8#issuecomment-1496812296_

I could be doing something wrong, but I need a sanity check. I went and installed raspberry pi os lite, then ssh'd into it and run the kiauh script to install klipper, moonraker, and fluidd. Then I transfer the cfg to ~/klipper/config and then transfer the config to ~/klipper. After that I run the make menuconfig, quit, then make. Then to make sure I didn't miss something I transferred and ran the klippventurer.sh script from the installer repo. I've attatched the output. It seems I have missed a step or something is wonky because it says there is no klipper.bin.
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

ldw300, 2023-04-22:
So an update on my side. I was able to get everything mostly going on my side but I used the RPI Imager to image an SD card with MainsailOS with Klipper, moonraker, etc. already installed. Compiled klipper.bin successfully, But when trying to flash the main board I get an error, failed to init device and klippy states it is unable to connect to the mcu. I'm still trying to sort this out myself but if there is any insight on this it would be helpful. Below are some screenshots of what I have encountered.

It is also very possible I have screwed up my soldering. I'm about to check my work to verify I'm not being an idiot.

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

VioSynthax, 2023-04-24:
Greetings!

My apologies for missing your issue at first, I'm traveling but will return home later this week.
```
sudo sh -c "echo '# Enable UART port' >> /boot/config.txt"
sudo sh -c "echo 'enable_uart=1' >> /boot/config.txt"
sudo sh -c "echo 'dtoverlay=miniuart-bt' >> /boot/config.txt"
sudo sh -c "echo 'dtoverlay=disable-bt' >> /boot/config.txt"

sudo sed -i 's/console=tty1 //' /boot/cmdline.txt
sudo reboot
```
Did you run these commands on MainsailOS? You'll need to run them prior to running
 `sudo stm32flash -w ~/klipper.bin -R -i -18,23,18:-18,-23,18 /dev/ttyAMA0`

The installer repo isn't ready for primetime, just an early script with a lot of debug output that will eventually automate the process, but for now doesn't work.

ldw300, 2023-04-24:
No problem! I am just trying tôprovide input and help where I can. I do remember running those commands but I just re-ran them and tried to flash. Still no go.  When running the flashing command the mainboard and fans switch off twice. Is this normal behavior? Going to verify my soldering in a bit and if it seems okay, I'll reflash an sd card and run kaiuh from scratch and retry the steps.

VioSynthax, 2023-04-26:
> No problem! I am just trying to provide input and help where I can. I do remember running those commands but I just re-ran them and tried to flash. Still no go. When running the flashing command the mainboard and fans switch off twice. Is this normal behavior? Going to verify my soldering in a bit and if it seems okay, I'll reflash an sd card and run kaiuh from scratch and retry the steps.
>
> Edit: After checking and improving soldering, I realized the DFU wire was on wrong GPIO pin, but after correcting issue, still having the same result. I'm going to re-flash the SD and start from scratch.

have you checked your RST point to make sure it it bridged to GND? I don't think your OS is the concern, reflashing probably won't help. You may want to start a minicom session and verify your UART lines are working by bridging RX and TX together (with local echo off) you can check it by bridging the points and then typing into the terminal, if you get nothing at all when they're apart but you get your input echoed back to you when they're crossed, then the serial UART is working. If it types when apart or doubles the input when together, then you have local echo on. Let me know how that goes. Once I get back home, I can run through the setup again and see if there's any little detail the guide is missing. Oh, and can you take some good clear photos of your installation?

ldw300, 2023-04-27:
So I did end up starting from scratch on the OS, this time I just installed 32bit PI OS, ran KAIU. Installed Klipper, Moonraker, and Fluidd. Ran through the setup process again and got the same results.

I double checked my RST pin to GND with a multimeter and I have good continuity. I did notice I had some solder bridges when reviewing the photos. (I had removed the Mediatek board previously trying to follow the old method.) So I cleaned up the solder bridges. Then tried a reflash. I got the same errors I have been receiving.

 I run through your request with the UART communication with minicom with local echo off. UART is working properly. I feel like I am missing a simple vital step somewhere and plan to read through everything again.

I apologize for the lighting quality in these photos, the main lighting in my office is bad, so I tried to make it visible with a flashlight. I can re-take and re-upload if needed.

For context there is some extra wires in the photos. The short grey wire on bottom is just an extra wire I added to the PRST pad to GND to make sure I had a good bridge since my soldering is terrible. The White wire and the Black wire going to and from the GND on the left side of the board comes from the buck converter and goes to the PI so it should be properly grounded everywhere.

 I tried to use the same color DuPont wires as in your photo for ease of troubleshooting. However I was afraid I was bridging pads with the stranded wires and my poor soldering skills, so I added some solid core wires to make an easier connection to the solder pads and soldered them to the DuPont wires.

Last photo is for GPIO validation to make sure I didn't make another mistake.

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

VioSynthax, 2023-04-27:
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

Swap TX and RX on the Pi side and give it another try, they appear to be switched around.

ldw300, 2023-04-27:
I have tried swapping them out of curiosity and still got the "failed to init device" message, and no communication to fluidd.

I removed all the mods and tried to return the ad3 to stock but it seems as if the board has been partially flashed or it is dead because lcd comes on but nothing ever shows up on it and the main board fan isn't running like it usually does.

VioSynthax, 2024-02-28:
Should be fixed after

> I have tried swapping them out of curiosity and still got the "failed to init device" message, and no communication to fluidd.
>
> I removed all the mods and tried to return the ad3 to stock but it seems as if the board has been partially flashed or it is dead because lcd comes on but nothing ever shows up on it and the main board fan isn't running like it usually does.

I think I may finally know what's causing this issue. I hadn't noticed this before, but you have a slightly different microcontroller than every other Adventurer 3 I've seen so far. I know the Adventurer 4 and 5M have this one, but didn't know it ever made it into any other than the Adventurer 3 Pro 2. Is this one also an SZ16 mainboard? The model number is in the top left by the motor controllers. If I can get this working on your Adv3, then I'm confident that I can support the Adventurer 4 and Pro 2 as well.

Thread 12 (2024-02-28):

Adventurer 4 Support

VioSynthax, 2024-02-28:
Add support for the FlashForge Adventurer 4 and rebrands (MonoPrice Voxel Pro)

VioSynthax, 2024-02-29:
Needs a pinout for initial support. UARTS, heaters, thermistors, fans, stepper enable/step/dir pins, multiplexer pins if one is present, etc.

Pull Requests encouraged.

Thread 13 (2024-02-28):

Support Adventurer 3 Pro 2

VioSynthax, 2024-02-28:
Add support for Adventurer 3 Pro 2

VioSynthax, 2024-02-29:
Needs a pinout for initial support. UARTS, heaters, thermistors, fans, stepper enable/step/dir pins, multiplexer pins if one is present, etc.

Pull Requests encouraged.

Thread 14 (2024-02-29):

Support Adventurer 3 CPU (MediaTek MT7688) U-boot and system image

VioSynthax, 2024-02-29:
Before the functions tied to the Linux side of the board will work, we need some software running on it to communicate with the Pi. This is also a vital prerequisite for #1 so we can do this plug-and-play style and forward the commands through ethernet instead of directly wired serial. There are are two real options here, one of which I don't like. We can:

1. Create a script that just places the binaries we want onto the original rootFS, and replace the init script with our own so we have ultimate control over the firmware. This leaves all FlashForge files in place, and doesn't touch your serial number, MAC address, print time, etc. etc.
2. Replace the old version of U-boot with our own, upstream, modern version with USB recovery and USB booting so the printer is essentially impossible to brick in a way that requires disassembly to fix. This doesn't preclude option 2, we can still boot normal stock firmware from the eMMC, and we can even recover stock firmware without it having to be bootable to do so. As it stands right now, if you can't boot, you can't fix it without some hefty skills. This is all fairly [X1 Plus style](https://www.x1plus.net/). We can then build a new rootFS from scratch with the latest supported version of the Linux kernel, OpenWRT, and all its packages. This makes sure that we have all the latest security updates, and we have ultimate control over what our firmware is doing and how new our build is. We can even USB boot this, so we can leave the eMMC completely untouched and stock, and with our custom U-boot we could recover the stock firmware even if it did get corrupt.

I feel that option 2 is the clear winner. It keeps the original firmware on the eMMC untouched, and only involves installing an updated version of the existing U-boot bootloader the printer ships with. For those with bricked Adventurer 3s, a secondary installation option to install using a SOIC clip or via the original bootloader's UART will be available to get them back up and running with either stock firmware or our open source firmware.

Unfortunately, while supporting a completely unmodified mainboard is possible, it won't be possible to do without adding some additional horsepower. A Raspberry Pi or some other kind of SBC or print host will be necessary to run Klipper. The CPU onboard the Adventurer 3 could certainly run Klipper, but due to it being written in Python there's absolutely no way Klippy is running on a system with only 64MB of RAM. This goes for the Adventurer 4 as well, just not enough RAM for hosting Klippy. ESPECIALLY with Mainsail and Fluidd and KlipperScreen. What I do think they can handle, is forwarding the command queue to the MCU and running KlipperScreen. I don't know what the experience will be like on the Adventurer 3's tiny screen, but the resolution at least does seem to be supported in KlipperScreen, so we'll just have to wait and see.

VioSynthax, 2024-02-29:
The list of features handled by the onboard processor include the LCD and touchscreen, piezo buzzer, front USB port, filament runout sensor, internal USB (camera) and the ethernet port.

rsnodgrass, 2024-06-26:
Agreed, option 2 sounds like a preferred way forward. I read over how X1 Plus works and it is so nice to leave basically everything with the stock firmware alone so it is easy to revert back (e.g. if you need to sell the A3).

Really look forward to running Klipper on an external RPi without hardware modifying my A3. I would have already done your Klipper mods, but have had way too many other priority projects in line. As fun as breaking out my soldering iron for the A3 would be.

THANK YOU!

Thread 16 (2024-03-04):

Support FF Creator Pro 2 IDEX ?

StijnMut, 2024-03-04:
Will the flashforge creator pro 2 get support via this project. I’ve been wanting to enable klipper on my machine for a long time but haven’t yet found an accessible way to do so.

The-Synthax, 2024-03-04:
> Will the flashforge creator pro 2 get support via this project. I’ve been wanting to enable klipper on my machine for a long time but haven’t yet found an accessible way to do so.

Eventually. I currently plan on supporting as many of the FlashForge printers as possible, I just need to have one in my possession to reverse engineer it and test.
Looks like it should be possible to install Klipper via the SD card slot on CP2. LCD definitely won’t work without connecting it to a Pi or making some changes to Klipper, but maybe if the machine has an easy Klipper installer then someone with the skills necessary will come along and write a Klipper module for driving displays.

StijnMut, 2024-03-05:
Sounds absolutely great.  Is there any way i can help with the development of this.   I don’t have much experience with coding but would love to help.  Maybe testing some early builds or something

The-Synthax, 2024-03-17:
> Sounds absolutely great. Is there any way i can help with the development of this. I don’t have much experience with coding but would love to help. Maybe testing some early builds or something

I may be able to make some test builds for CP2 once the Adventurers are printing, thankfully someone has made a pin map so I **might** be able to make some test builds without physically having one of these on hand. It would be very difficult to make a full printer config without having one for testing, so someone else would need to tune the printer if I can't find an affordable used or broken one.

StijnMut, 2024-03-17:
Ive found another person using klipper on the creator pro 2 and he has uploaded a klipper config file however i dont really know how he git it installed.
Maybe the config files will help ?
Foud these files on his website:

[Klipper CP2 Files from eazrael.zip](https://github.com/synthread/Klippventurer/files/14627134/Klipper.CP2.Files.from.eazrael.zip)

The-Synthax, 2024-03-17:
> Ive found another person using klipper on the creator pro 2 and he has uploaded a klipper config file however i dont really know how he git it installed. Maybe the config files will help ? Foud these files on his website:
>
> [Klipper CP2 Files from eazrael.zip](https://github.com/synthread/Klippventurer/files/14627134/Klipper.CP2.Files.from.eazrael.zip)

Installed using an STLink V2 or a clone it looks like. They're often $8-10 on Amazon and can be used to both recover from a bricked microcontroller or dump the contents of one for analysis. I would recommend making a dump before testing anything so you can restore the bootloader if it becomes corrupt. If you want to test, @ me in the #creator-pro-2 channel on Discord and I'll put together a test build for you. Should be possible to install it in a way that allows for easily returning to stock firmware.

StijnMut, 2024-03-17:
Alright I'll order one on Amazon and will try to dump the original first.   I'll @ you when I get to this point.  I don't have much experience with directly flashing firmware to the controllers itself.

cb-agotchi, 2024-03-24:
https://github.com/cb-agotchi/Flashforge-Creator-Pro-2-Configs

https://youtu.be/mIQjz5eHBBo?si=pjdYA_gWlI6WW3qT

I got the Dockterj fork of Klipper working on my FFCP2. Since then something has changed and it wouldn't resolve the ADS1118 so I added an rp2040 and 3950's for temperature duty.

First link is my confirmed working printer.cfg, macros.cfg and orca profile using a RatRig VCast as the base profile.

Hopefully this is helpful as a pinout reference for you guys to build off of.

eazrael, 2024-05-09:
Hi, if you are still working on this. Complete documentation including pin mapping (mostly) are in my wiki https://wiki.evilazrael.de/en/flashforge-creator-pro-2 . Klipper mods are in the two branches ffcp and ffcp_basic at https://github.com/eazrael/klipper/. Just take what you need.

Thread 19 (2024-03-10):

Config issues...

3Dgraf64, 2024-03-10:
Hi!  Thank you for your work on this project.  I'm a totally noob in Linux.  That's why I rely on you.  Adventurer3 machine here.
A note on your readme.md instruction:
  The command "git clone https://github.com/synthread/Klippventurer.git ~" doesn't work as it is.  Linux gives an error as it tries to overwrite the "pi" directory.  You must remove the "~" (tilde) at the end of the command.

Next when flashing the controller I got the following response:

http://stm32flash.sourceforge.net/

Using Parser : Raw BINARY
Interface serial_posix: 115200 8E1

GPIO sequence start
 setting gpio 18 to 0... OK
 delay 100000 us
 setting gpio 23 to 1... OK
 delay 100000 us
 setting gpio 18 to 1... OK
GPIO sequence end

Got byte 0x01 instead of ACK
Unexpected reply from device on command 0x02

GPIO sequence start
 setting gpio 18 to 0... OK
 delay 100000 us
 setting gpio 23 to 0... OK
 delay 100000 us
 setting gpio 18 to 1... OK
GPIO sequence end

Then fluid won't connect to the controller.  I verified my wiring more than twice.
Any tip to resolve this?  GD32F103RCT6 controller
Anything in the make menuconfig command specific to this controller?
Is it better to remove the Mediatek board?

Thanks!
Francis

The-Synthax, 2024-03-11:
the GD32 has been the easiest MCU to work with so far. The only one I know requires a different .config is the Nation branded ones.

Can you share some photos of your soldering? A clear view of both ends of each wire would be most helpful.  Can you also confirm that your LCD remains off during all of this, with no backlight or splash screen?

3Dgraf64, 2024-03-11:
Yes.  The display stays blank.  The fans too.
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

The-Synthax, 2024-03-11:
The white screen is making me think that the MediaTek chip is interfering with the UART. Maybe the RST in the diagram I have is insufficient to prevent this? You can try the following jumper instead, which will definitely get the MediaTek system out of the way and we'll know for sure if this is the cause.
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

3Dgraf64, 2024-03-11:
Definitely.  The Mediatek seem to interfere. After installing this jumper and sending the flash command many times I get random massages: "Failed to read ACK byte", "Got byte 0x01 instead of ACK Unexpected reply from device on command 0x02", "Failed to init device.".  This time the buzzer make some clicks while executing the command.

The-Synthax, 2024-03-12:
> Definitively. The Mediatek seems to interfere. After installing this jumper and sending the flash command many times I get random massages: "Failed to read ACK byte", "Got byte 0x01 instead of ACK Unexpected reply from device on command 0x02", "Failed to init device.", "GET returns unknown commands (0x79) Failed to read ACK byte". This time the buzzer make some clicks while executing the command.

I was able to replicate this issue and solved it in my case. Could you run the following commands on your Pi and see if it fixes the issue for you as well?

`sudo sed -e s/ console=serial0,115200//g -i /boot/cmdline.txt`
`sudo stm32flash -w ~/klipper/out/klipper.bin -R -i -18,23,18:-18,-23,18 /dev/ttyAMA0`

3Dgraf64, 2024-03-12:
I copied an pasted the first line and this is the response to the sed command:  "sed: -e expression #1, char 2: unterminated `s' command".  There must be something wrong.

The-Synthax, 2024-03-12:
> I copied an pasted the first line and this is the response to the sed command: "sed: -e expression #1, char 2: unterminated `s' command". There must be something wrong.

My bad, typo'd that line. try `sudo sed -e s/\ console=serial0,115200//g -i /boot/cmdline.txt` then reboot `sudo reboot` before you use stm32flash.

>Edit: I redid all the procedure ending with the same random message results. Is it possible I bricked my controller?

The controller is definitely "bricked" (no working program is written to the storage), but both the MediaTek board and the Pi flash the entirety of the onboard storage every time it needs an update anyway. A microcontroller like these can never truly be bricked as their bootrom is burned into the silicon. If you remove your Pi and all wiring, the FlashForge firmware would reinstall the original MCU binary and you'd be back to stock.

The-Synthax, 2024-03-12:
if you're still having issues and it won't flash after a few attempts, can you do `cat /boot/cmdline.txt` and `cat /boot/config.txt` and give me the output of those?

3Dgraf64, 2024-03-12:
So.  What I did:  Remove all wires and reboot the print letting it "repairs" itself at least 5 time without success.
Now all wires are back.  Tried again the flash command without success.
First cat command returns:  "console=serial0,115200 console=tty1 root=PARTUUID=eb41f98d-02 rootfstype=ext4 fsck.repair=yes rootwait cfg80211.ieee80211_regdom=CA"
Second cat command returns:  "# For more options and information see
# http://rpf.io/configtxt
# Some settings may impact device functionality. See link above for details

# uncomment if you get no picture on HDMI for a default "safe" mode
#hdmi_safe=1

# uncomment the following to adjust overscan. Use positive numbers if console
# goes off screen, and negative if there is too much border
#overscan_left=16
#overscan_right=16
#overscan_top=16
#overscan_bottom=16

# uncomment to force a console size. By default it will be display's size minus
# overscan.
#framebuffer_width=1280
#framebuffer_height=720

# uncomment if hdmi display is not detected and composite is being output
#hdmi_force_hotplug=1

# uncomment to force a specific HDMI mode (this will force VGA)
#hdmi_group=1
#hdmi_mode=1

# uncomment to force a HDMI mode rather than DVI. This can make audio work in
# DMT (computer monitor) modes
#hdmi_drive=2

# uncomment to increase signal to HDMI, if you have interference, blanking, or
# no display
#config_hdmi_boost=4

# uncomment for composite PAL
#sdtv_mode=2

#uncomment to overclock the arm. 700 MHz is the default.
#arm_freq=800

# Uncomment some or all of these to enable the optional hardware interfaces
#dtparam=i2c_arm=on
#dtparam=i2s=on
#dtparam=spi=on

# Uncomment this to enable infrared communication.
#dtoverlay=gpio-ir,gpio_pin=17
#dtoverlay=gpio-ir-tx,gpio_pin=18

# Additional overlays and parameters are documented /boot/overlays/README

# Enable audio (loads snd_bcm2835)
dtparam=audio=on

# Automatically load overlays for detected cameras
camera_auto_detect=1

# Automatically load overlays for detected DSI displays
display_auto_detect=1

# Enable DRM VC4 V3D driver
dtoverlay=vc4-kms-v3d
max_framebuffers=2

# Disable compensation for displays with overscan
disable_overscan=1

[cm4]
# Enable host mode on the 2711 built-in XHCI USB controller.
# This line should be removed if the legacy DWC2 controller is required
# (e.g. for USB device mode) or if USB support is not required.
otg_mode=1

[all]

[pi4]
# Run as fast as firmware / board allows
arm_boost=1

[all]
enable_uart=1
dtoverlay=miniuart-bt
dtoverlay=disable-bt".

The-Synthax, 2024-03-12:
Looks like the Pi is still outputting its serial console to the UART, so it’s interrupting the flashing process. Try `sudo raspi-config` then interfaces>serial. Turn off console output and turn on serial, then reboot. Hopefully this will do the trick.

3Dgraf64, 2024-03-12:
We did a step!  The flash works!
Now I have to do the config files.  This should be a formality
Thanks again!
How can I donate?

The-Synthax, 2024-03-17:
> We did a step! The flash works! Now I have to do the config files. This should be a formality Thanks again! How can I donate?

Great to hear! Have you had success printing with Klipper yet? Let me know if you need any additional assistance, I'm happy to help 😄

We're waiting to hear back from GitHub to be able to accept direct donations. I really appreciate your willingness to donate, all donations go toward helping us get unsupported printers to port the project to.

3Dgraf64, 2024-03-18:
See yourself!
https://youtube.com/shorts/udvLeUi6mUE?feature=share
https://youtube.com/shorts/5JvzBNBNM6Y?feature=share

3Dgraf64, 2024-03-19:
See yourself!
https://youtube.com/shorts/udvLeUi6mUE?feature=share
https://youtube.com/shorts/5JvzBNBNM6Y?feature=share

The-Synthax, 2024-03-22:
> See yourself! https://youtube.com/shorts/udvLeUi6mUE?feature=share https://youtube.com/shorts/5JvzBNBNM6Y?feature=share I did the E3D mod from u/Br0kenScreen (Reddit). Now I can PID tune the hotend. Both bed and hotend can't be pre-heated simultaneously because of the weakness of the power supply. Still tweaking the Orca's profile. Maybe a linear rail mod for the Y axis in the future...

Looking good! Is that hotend getting you much more flow than the original or are you still bottlenecked by the extruder?

A linear rail mod would be amazing! Dual linear rails may be possible, maybe with a drilling jig to mount them nice and parallel? That may even free up space underneath for dual Y motors if you really want to push the speeds.

I'm currently planning to release a Stealthburner / Dragon Burner mount for this printer as well as a bracket that uses the extruder mounting holes for a reverse Bowden tube and BTT U2C. Dual linear rails may be possible, maybe with a drilling jig to mount them nice and parallel? That may even free up space underneath for dual Y motors if you really want to push the speeds.

Update on the donations situation: We're still waiting to hear back from GitHub about the GitHub Sponsors program, but in the meantime we've opened a Ko-Fi page for anyone who wants to support the project. It's live now on the main repo page or at https://ko-fi.com/synthread ❤️

3Dgraf64, 2024-03-22:
Bottlenecks are the fans.  Only 3010.  Cooling is an issue but better than the orginal toolhead.  A mini Stealthburner or Dragonburner would be great.  Next, the extruder.  I raised the current by 100ma.  Have to test with a CHT nozzle.

Before getting into linear rails I have to do some test printing the same part in each corner of the bed since it's driven from the left side.

ko-fi done!

Thanks again!

The-Synthax, 2024-03-23:
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

Did you swap out your extruder spring for a stiffer one or print the spacer? If not I’m impressed you’re managing to need more torque. I thought my motor was skipping originally but upon closer inspection, it was actually the idler, the motor wasn’t losing any steps on mine until I put so much tension on it I was squashing PLA till it looked like linguine.

3Dgraf64, 2024-03-27:
Yes, I installed the spacer.  The motor is skipping.  I realized that the extruder motor is heating enough to melt the filament.  Causing blockages.  Probably the cause of your linguine filament.  I had set the running current to 0.9 but I brought it back to 0.8.  I’m toying with the idea of building a Voron M4 extruder now.

The-Synthax, 2024-03-27:
> Yes, I installed the spacer. The motor is skipping. I realized that the extruder motor is heating enough to melt the filament. Causing blockages. I got linguine too. I had set the running current to 0.9 but I brought it back to 0.8. I’m toying with the idea of building a Voron M4 extruder now.

That'd be a fantastic upgrade! BTW, are you in our Discord server? If you use Discord I'd like to add you to our list of supporters in our server.

3Dgraf64, 2024-03-27:
Yes!  I use it as gravel3170.  Just give me the link.

The-Synthax, 2024-03-27:
> Yes! I use it as gravel3170. Just give me the link.

https://discord.gg/ns2pFdhdMW

Closed 2024-03-22.

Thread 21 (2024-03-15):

Support for Adventurer 5m/ 5m Pro.

mBlinkii, 2024-03-15:
Hello, will there also be a manual for the Adventurer 5m/ 5m Pro. can you get any help with this? I have a 5m and can help/ test.

The-Synthax, 2024-03-17:
Hey there!

We do plan on supporting the 5M (and Pro) eventually, but the current focus is full feature support for the Adventurer 3. Due to the similarity between these machines and the other Adventurers, once the 3 is fully supported, supporting the others won't take nearly as long.

As for how you can help, watch this repo and/or join our Discord for when we start testing on 5M. I won't be able to afford one for a while to port the project to, but the machine does run a custom fork of Klipper from the factory as far as I know, and there is another project working on bringing fully open firmware to the 5M/Pro here https://github.com/xblax/flashforge_adm5_klipper_mod

mBlinkii, 2024-03-17:
Yes, I already knew about the mod, but the AD5M hardware is too weak for more functions. That's why I wanted to connect an RPI to the hardware.

I think I will follow these instructions and give it a try.
https://github.com/g992/flashforge-ad5m-5mpro-research/blob/main/upgrades/klipper_on_ext_cpu.md

The-Synthax, 2024-03-17:
> Yes, I already knew about the mod, but the AD5M hardware is too weak for more functions. That's why I wanted to connect an RPI to the hardware.
>
> I think I will follow these instructions and give it a try. https://github.com/g992/flashforge-ad5m-5mpro-research/blob/main/upgrades/klipper_on_ext_cpu.md

These instructions are incredibly similar to the method currently published here for the 3, so should work okay enough on the 5M. The only issue with this method is that you lose the any functions that rely on the CPU, which on the 3 includes the screen, camera, USB, filament runout sensor, and speaker/buzzer. Since the CPU is incredibly similar to the 4, our easy installer for the 4 will work on the 5m with almost no modification.

I had theorized that the CPU and RAM onboard the 5 couldn't handle much more than basic functionality, but didn't have any solid evidence of that. What limitations are you running into with the onboard Klipper?

mBlinkii, 2024-03-17:
Currently it is still a very early version, KlipperScreen does not work reliably, the camera does not always work.

For example Obico or Mobileraker. I think that will be too much for the hardware.

The-Synthax, 2024-03-23:
Seeing as it only has 128MB of RAM, I'm really surprised it can handle both Klippy and KlipperScreen at the same time. We're working on a firmware for Adventurer 3 that acts as a server to forward all the necessary interfaces to a Raspberry Pi or other Klippy host computer. Both ARM and MIPS builds of it will release simultaneously, so Adventurer 5M should be able to run it as well as the 3 and 4. It won't have support initially for driving the screen from the Pi, but is planned.

mBlinkii, 2024-03-23:
> Seeing as it only has 128MB of RAM, I'm really surprised it can handle both Klippy and KlipperScreen at the same time. We're working on a firmware for Adventurer 3 that acts as a server to forward all the necessary interfaces to a Raspberry Pi or other Klippy host computer. Both ARM and MIPS builds of it will release simultaneously, so Adventurer 5M should be able to run it as well as the 3 and 4. It won't have support initially for driving the screen from the Pi, but is planned.

That sounds very good, the internal display does not necessarily have to work. i would probably connect a display to the pi and use it.

mBlinkii, 2024-03-25:
I'm really looking forward to it, I've been waiting with the hardware mod. I will be using a larger display as I find it too small for Klipper Screen. The UI is too small to use it properly. I think for such a small display you would have to develop a custom UI.

I am ready to test it on the 5M. I don't have any problems with it if something goes wrong. I will know how to help myself.

xblax, 2024-03-25:
> I'd like to get it in public hands ASAP, but we're putting a lot of effort into the installer's reliability, reversibility, and general safety net to try to improve the chances that if something does go wrong, you don't need to be a Linux guru or IT professional to fix the printer's OS, it'll just give you an error and fail gracefully back to stock firmware.

You may want to have look at the install script that I wrote for the other mod mentioned here, in case you also use a chroot based approach:
https://github.com/xblax/flashforge_adm5_klipper_mod/blob/master/device_files/install/flashforge_init.sh
https://github.com/xblax/flashforge_adm5_klipper_mod/blob/master/build_overlay/common/etc/init/S00klipper_mod

It is pretty fail-safe. Only the mod files / chroot are copied to printer and then a single init script is installed the "host" linux system.

In general you might find some of the reverse engineered things, like the functions of the load cell tare mechanism or MCU boot code helpful if you plan to add support for the 5M to your mod.

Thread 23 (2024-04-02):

A5MP board wiring diagram & LED indicators

3DThingy, 2024-04-02:
Sharing these diagrams I got from FF while diagnosing blinking lights problem while the bed is heating.

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

More about the blinking lights issue: It was never resolved. I don't think anyone has noticed or discussed this issue before, but when the bed is heating and at temp. close to the set bed temp. the relay and the LED indicator D12 will continuously turn on and off causing the light to blink..They weren't able to resolve it, but I do believe it's a firmware issue.

The-Synthax, 2024-04-13:
Thank you for sharing. The blinking lights aren't an issue, and any noise you hear from the bed mosfet and coils is normal. This isn't a separately controlled LED for the status, it's powered directly by the bed mosfet in parallel to the bed itself when the fet is triggered. Power is controlled via PWM, so it's only ever either fully on or fully off, with temperature controlled by the amount of time it is on, also called "duty cycle". Firmware can't make it not behave this way, as there isn't any hardware onboard for controlling the bed in an analog fashion. The nozzle and fans all work this way as well.

Closed 2024-04-12.

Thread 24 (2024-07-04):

Adventurer 3 Support Status

SoCuul, 2024-07-04:
Hey @The-Synthax! Absolutely love the work you've done here, you're seriously talented. I'm wondering if there's been any update on the status of the camera, which is the only feature I think I'd really be missing.

Additionally, has the setup with the Adventurer 3 (non-pro) been pretty much smooth sailing after setup in your experience? Mostly just wanting to make sure that all the green checked features are working at a good level before I try this on several priters.

Closed 2024-10-08.

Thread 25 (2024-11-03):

Orca slicer

joey00797, 2024-11-03:
hi dear. i updated my printer according to your instructions, and now it's time to print. how to add your profile about orca slicer? or how to solve the problem with my profile, all my models are generated on 0.0 coordinates. and the printer does not print.

Closed 2024-11-03.

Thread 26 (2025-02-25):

Active Development?

jjuuzzii, 2025-02-25:
Is the Project still in Aktive development?
Will the adventure 3 eventually be fully compatible?

MaizeShark, 2025-08-19:
Fully compatible is probably never really possible without any modifications.

It is as far as i am aware still in development, last i really heard from Kai (It “works” now but I’m just hesitant about releasing it since I don’t want to brick anyone’s stuff and have it be my fault instead of theirs :P) was on the 23.03.25 that the solderless method is finished but he/she doesnt want to brick peoples printers and that he/she now actively on the nation mcu support. Idk when it will be released but for updates you should def join the discord server(https://discord.gg/3DPtKxb86Y).

solderless would mean that you can use klipper without soldering (i think it will be via ethernet). What is/will be supported by this i have no idea, just that N32 MCUs will be supported as well as the others.

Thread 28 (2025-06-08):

Creator 3 and Guider 3 Klipper - want to contribute

ovDarkness, 2025-06-08:
Hi,
I have experience with 3D printers (8+ years) and I'm quite capable regarding electronics, embedded amd mechanics.
I also happen to have damaged Cr3 an G3.
How can I start (no Klipper experience) to help?

MaizeShark, 2025-08-19:
[Discord](https://discord.gg/3DPtKxb86Y) ;)

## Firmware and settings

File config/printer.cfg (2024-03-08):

# This file contains pin mappings for Adventurer 3 and MonoPrice Voxel with SZ16 mainboard
# There may be versions of these printers that require slight modifications to the config.
# To use this config, the firmware should be compiled for the STMicroelectronics STM32,
# Processor model STM32F103, Clock Reference 12 MHz crystal, Serial on USART1 PA10/PA9.
# To install Klipper, you must follow the steps as described here:
# https://github.com/synthread/Klippventurer

# See docs/Config_Reference.md for a description of parameters.
# If you have TMC2209 drivers (like Adventurer 3 Pro) replace all instances of TMC2208 in this config with TMC2209
[include adv3-macros.cfg]
[include fluidd.cfg]
[include KAMP_Settings.cfg]
[exclude_object]

[mcu]
serial: /dev/ttyAMA0
baud: 250000
restart_method: command

[printer]
kinematics: cartesian
max_velocity: 800
square_corner_velocity: 6
max_accel: 6500
max_z_velocity: 30
max_z_accel: 400

[stepper_x]
step_pin: PB8
dir_pin: !PB9
enable_pin: !PB7
microsteps: 32
rotation_distance: 33.9
endstop_pin: ^PC14
position_endstop: 159 # Set this to the distance between the endstop trigger point and touching the left side of the axis
position_max: 161 # Set this to the distance between the endstop and touching the right side of the axis, PLUS position_endstop
position_min: 0 # Leave this alone
homing_speed: 75

[stepper_y]
step_pin: PC1
dir_pin: !PC2
enable_pin: !PC0
microsteps: 32
rotation_distance: 33.9
endstop_pin: ^PB3
position_endstop: 4 # Set this to the distance between the endstop trigger point and touching the back side of the axis
position_max: 151 # Set this to the distance between the endstop and touching the front side of the axis
homing_speed: 75

[stepper_z]
step_pin: PC8
dir_pin: !PC9
enable_pin: !PC7
microsteps: 16
rotation_distance: 6.25
endstop_pin: !PC13
position_min: -2 # This is slightly lower than the bed surface to allow for mesh leveling
#position_endstop: 148 # Leave this alone, use fluidd to calibrate your Z offset.
position_max: 155 # Set this to the distance between the endstop trigger point and touching the top of the axis. If you see the axis skew diagonally at this position, it's too high
homing_speed: 25
second_homing_speed: 15

[thermistor adv3_ntc]
temperature1: 19
resistance1:  123000
temperature2: 79
resistance2:  5820 
temperature3: 230
resistance3:  255 

[extruder]
step_pin: PA1
dir_pin: PA2
enable_pin: !PA3
microsteps: 16
rotation_distance: 33.5
nozzle_diameter: 0.3
filament_diameter: 1.750
heater_pin: PA8
sensor_type: adv3_ntc
sensor_pin: PA5
min_temp: -237.15
max_temp: 500
max_extrude_only_distance: 550
max_extrude_only_velocity: 2000
max_extrude_cross_section: 5
pressure_advance: 2.1
pressure_advance_smooth_time: 0.1

[heater_bed]
heater_pin: PC6
sensor_type: adv3_ntc
sensor_pin: PC4
min_temp: 0
max_temp: 110

[temperature_sensor mcu_temp]
sensor_type: temperature_mcu
#this is the operational temperature range of STM32f103
min_temp: -40
max_temp: 85

# Part cooling fan and heatbreak fan
[fan]
pin: PB10
cycle_time: 0.1

# Mainboard cooling fan
[controller_fan mainboard]
pin: PA4
heater: extruder, heater_bed

# Chamber ventilation fan
[fan_generic chamber_fan]
pin: PB13
cycle_time: 0.1

[output_pin led]
pin: PB12
value: 1
pwm: true
cycle_time: 0.008333 # This PWM frequency should stop the LED from flickering on video

[homing_override]
axes: zxy
gcode:
 g28 z
 g28 x
 g28 y

[bed_mesh]
speed: 100
horizontal_move_z: 5
mesh_min: 5, 5
mesh_max: 150, 145
probe_count: 3, 3
fade_start: 1
fade_end: 10
fade_target: 0

[input_shaper]
shaper_freq_x: 205
shaper_type: mzv
shaper_freq_y: 197.126
shaper_type: ei

[firmware_retraction]
retract_length: 3.8
retract_speed: 25
unretract_extra_length: 0
unretract_speed: 25

########################################
# TMC2208 configuration
########################################

[tmc2208 stepper_x]
uart_pin: PC10
select_pins: !PB0, !PB1, !PD1
run_current: 0.600
sense_resistor: 0.220
stealthchop_threshold: 999999

[tmc2208 stepper_y]
uart_pin: PC10
select_pins: PB0, !PB1, !PD1
run_current: 0.600
sense_resistor: 0.220
#we use SpreadCycle on this axis due to the weight of the bed and print.

[tmc2208 stepper_z]
uart_pin: PC10
select_pins: !PB0, PB1, !PD1
run_current: 0.600
sense_resistor: 0.220
stealthchop_threshold: 999999

[tmc2208 extruder]
uart_pin: PC10
select_pins:  PB0,  PB1, !PD1
run_current: 0.800
sense_resistor: 0.220

#*# <---------------------- SAVE_CONFIG ---------------------->
#*# DO NOT EDIT THIS BLOCK OR BELOW. The contents are auto-generated.
#*#
#*# [extruder]
#*# control = pid
#*# pid_kp = 27.403
#*# pid_ki = 9.615
#*# pid_kd = 19.524
#*#
#*# [heater_bed]
#*# control = pid
#*# pid_kp = 71.615
#*# pid_ki = 3.913
#*# pid_kd = 327.640
#*#
#*# [stepper_z]
#*# position_endstop = 151.315
#*#
#*# [bed_mesh default]
#*# version = 1
#*# points =
#*# 	-0.088984, 0.127813, 0.323125
#*# 	0.037969, 0.155156, 0.278203
#*# 	0.049688, 0.164922, 0.266484
#*# x_count = 3
#*# y_count = 3
#*# mesh_x_pps = 2
#*# mesh_y_pps = 2
#*# algo = lagrange
#*# tension = 0.2
#*# min_x = 5.0
#*# max_x = 150.0
#*# min_y = 5.0
#*# max_y = 145.0

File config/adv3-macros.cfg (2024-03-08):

[gcode_macro START_PRINT]
gcode:
    {% set BED_TEMP = params.BED_TEMP|default(60)|float %}
    {% set EXTRUDER_TEMP = params.EXTRUDER_TEMP|default(190)|float %}
    # Start bed heating
    M140 S{BED_TEMP}
    # Start nozzle heating
    M104 S{EXTRUDER_TEMP}
    # Use absolute coordinates
    G90
    # Reset the G-Code Z offset (adjust Z offset if needed)
    SET_GCODE_OFFSET Z=0.0
    # Home the printer
    G28
    Smart_Park
    # Wait for bed to reach temperature
    M190 S{BED_TEMP}
    # Set and wait for nozzle to reach temperature
    M109 S{EXTRUDER_TEMP}
    Line_Purge

[gcode_macro END_PRINT]
gcode:
    G10 # Retract
    G90 # Use absolute positioning
    G1 X161 Y154 F7500 # Move X/Y away from print
    G1 Z154 F30 # Move Z away from print
    # Turn off bed, extruder, part cooling fan, and chamber fan
    M140 S0
    M104 S0
    M106 S0
    SET_FAN_SPEED  FAN=chamber_fan SPEED=0.00
    # Disable steppers
    M84

[gcode_macro CANCEL_PRINT]
gcode:
    END_PRINT
    
[gcode_macro FILAMENT_LOAD]
gcode:
 M106
 M109 S230
 M83                    # Put the extruder into relative mode
 G92 E0.0               # Reset the extruder position to zero
 G1 E465 F1500          # Move the extruder forward 465mm at a speed of 1500mm/minute
 G1 E25 F150            # Slow down for the last 25mm to 150mm/minute
 G92 E0.0               # Reset the extruder again
 M82                    # Put the extruder back into absolute mode.
 M104 S0

[gcode_macro FILAMENT_UNLOAD]
gcode:
 M106
 M109 S230
 M83                   # Put the extruder into relative mode
 G92 E0.0              # Reset the extruder position to zero
 G1 E-530 F2000        # Retract the filament 530mm at a speed of 2000mm/minute
 G92 E0.0              # Reset the extruder again
 M82                   # Put the extruder back into absolute mode.
 M107

[gcode_macro TEST_SPEED]
gcode:
    # Home, get position, throw around toolhead, home again.
    # If MCU stepper positions (first line in GET_POSITION) are greater than a full step different (your number of microsteps), then skipping occured.
    # We only measure to a full step to accomodate for endstop variance.
    # Example: TEST_SPEED SPEED=300 ACCEL=5000 ITERATIONS=10
    
    # Speed
    {% set speed  = params.SPEED|default(printer.configfile.settings.printer.max_velocity)|int %}
    # Iterations
    {% set iterations = params.ITERATIONS|default(5)|int %}
    # Acceleration
    {% set accel  = params.ACCEL|default(printer.configfile.settings.printer.max_accel)|int %}
    # Bounding inset for large pattern (helps prevent slamming the toolhead into the sides after small skips, and helps to account for machines with imperfectly set dimensions)
    {% set bound = params.BOUND|default(20)|int %}
    # Size for small pattern box
    {% set smallpatternsize = SMALLPATTERNSIZE|default(20)|int %}
    
    # Large pattern
        # Max positions, inset by BOUND
        {% set x_min = printer.toolhead.axis_minimum.x + bound %}
        {% set x_max = printer.toolhead.axis_maximum.x - bound %}
        {% set y_min = printer.toolhead.axis_minimum.y + bound %}
        {% set y_max = printer.toolhead.axis_maximum.y - bound %}
    
    # Small pattern at center
        # Find X/Y center point
        {% set x_center = (printer.toolhead.axis_minimum.x|float + printer.toolhead.axis_maximum.x|float ) / 2 %}
        {% set y_center = (printer.toolhead.axis_minimum.y|float + printer.toolhead.axis_maximum.y|float ) / 2 %}
        
        # Set small pattern box around center point
        {% set x_center_min = x_center - (smallpatternsize/2) %}
        {% set x_center_max = x_center + (smallpatternsize/2) %}
        {% set y_center_min = y_center - (smallpatternsize/2) %}
        {% set y_center_max = y_center + (smallpatternsize/2) %}

    # Save current gcode state (absolute/relative, etc)
    SAVE_GCODE_STATE NAME=TEST_SPEED
    
    # Output parameters to g-code terminal
    { action_respond_info("TEST_SPEED: starting %d iterations at speed %d, accel %d" % (iterations, speed, accel)) }
    
    # Home and get position for comparison later:
        M400 # Finish moves - https://github.com/AndrewEllis93/Print-Tuning-Guide/issues/66
        G28
        # QGL if not already QGLd (only if QGL section exists in config)
        {% if printer.configfile.settings.quad_gantry_level %}
            {% if printer.quad_gantry_level.applied == False %}
                QUAD_GANTRY_LEVEL
                G28 Z
            {% endif %}
        {% endif %} 
        # Move 50mm away from max position and home again (to help with hall effect endstop accuracy - https://github.com/AndrewEllis93/Print-Tuning-Guide/issues/24)
        G90
        G1 X{printer.toolhead.axis_maximum.x-50} Y{printer.toolhead.axis_maximum.y-50} F{30*60}
        M400 # Finish moves - https://github.com/AndrewEllis93/Print-Tuning-Guide/issues/66
        G28 X Y
        G0 X{printer.toolhead.axis_maximum.x-1} Y{printer.toolhead.axis_maximum.y-1} F{30*60}
        G4 P1000 
        GET_POSITION

    # Go to starting position
    G0 X{x_min} Y{y_min} Z{bound + 10} F{speed*60}

    # Set new limits
    SET_VELOCITY_LIMIT VELOCITY={speed} ACCEL={accel} ACCEL_TO_DECEL={accel / 2}

    {% for i in range(iterations) %}
        # Large pattern diagonals
        G0 X{x_min} Y{y_min} F{speed*60}
        G0 X{x_max} Y{y_max} F{speed*60}
        G0 X{x_min} Y{y_min} F{speed*60}
        G0 X{x_max} Y{y_min} F{speed*60}
        G0 X{x_min} Y{y_max} F{speed*60}
        G0 X{x_max} Y{y_min} F{speed*60}
        
        # Large pattern box
        G0 X{x_min} Y{y_min} F{speed*60}
        G0 X{x_min} Y{y_max} F{speed*60}
        G0 X{x_max} Y{y_max} F{speed*60}
        G0 X{x_max} Y{y_min} F{speed*60}
    
        # Small pattern diagonals
        G0 X{x_center_min} Y{y_center_min} F{speed*60}
        G0 X{x_center_max} Y{y_center_max} F{speed*60}
        G0 X{x_center_min} Y{y_center_min} F{speed*60}
        G0 X{x_center_max} Y{y_center_min} F{speed*60}
        G0 X{x_center_min} Y{y_center_max} F{speed*60}
        G0 X{x_center_max} Y{y_center_min} F{speed*60}
        
        # Small patternbox
        G0 X{x_center_min} Y{y_center_min} F{speed*60}
        G0 X{x_center_min} Y{y_center_max} F{speed*60}
        G0 X{x_center_max} Y{y_center_max} F{speed*60}
        G0 X{x_center_max} Y{y_center_min} F{speed*60}
    {% endfor %}

    # Restore max speed/accel/accel_to_decel to their configured values
    SET_VELOCITY_LIMIT VELOCITY={printer.configfile.settings.printer.max_velocity} ACCEL={printer.configfile.settings.printer.max_accel} ACCEL_TO_DECEL={printer.configfile.settings.printer.max_accel_to_decel} 

    # Re-home and get position again for comparison:
        M400 # Finish moves - https://github.com/AndrewEllis93/Print-Tuning-Guide/issues/66
        G28 # This is a full G28 to fix an issue with CoreXZ - https://github.com/AndrewEllis93/Print-Tuning-Guide/issues/12
        # Go to XY home positions (in case your homing override leaves it elsewhere)
        G90
        G0 X{printer.toolhead.axis_maximum.x-1} Y{printer.toolhead.axis_maximum.y-1} F{30*60}
        G4 P1000 
        GET_POSITION

    # Restore previous gcode state (absolute/relative, etc)
    RESTORE_GCODE_STATE NAME=TEST_SPEED

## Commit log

2022-05-15 Initial Commit
    add firmware file and config, partial guide
    [Adventurer-3.cfg]
2022-05-15 Added Pin Mod Diagram
2022-05-17 Silent when idle, all fans work
    Printer now is silent while idle and only enables the board cooling fan when steppers or heaters are enabled, unlike stock firmware. All 3 fans now work correctly.
    [Adventurer-3.cfg]
2022-05-18 LED support, StealthChop, +extruder current
    Print head LED now works, XYZ steppers now operate in StealthChop mode by default, increased extruder current as extruder stepper was still cold and still skipping steps, torque was way too low. Still well within limits and far below max temperature for these motors.
    [Adventurer-3.cfg]
2022-05-19 Fixed Y-axis being inverted
    [Adventurer-3.cfg]
2023-03-11 Fixed some mistakes in flashing STM32
    Removed bootloader section. STM32 contains a built-in bootloader in ROM that cannot be overwritten. It contains the features we need here and even a mechanism that should allow for automatic updates down the road.
2023-03-11 Delete STM32Duino.bin
    No longer recommended
2023-03-13 New (fixed) wiring diagram
    Improved diagram visually, fixed wiring mistake that lead to STM32 serial not connecting to the Pi. Added RST>GND jumper to disable MediaTek SOC.
2023-03-13 Delete klipper.bin
    No longer needed, install script will generate one automatically
2023-12-15 Update README.md
    general "Pi with Wi-Fi" recommendation, improved reset pin soldering instructions
2023-12-15 Update README.md
    Raspberry Pi (hardmod) version
2024-02-01 Fixed wiring diagram
2024-02-01 fix wiring diagram in README
2024-02-27 Added mount and spacer
    Mount for Raspberry Pi Zero 2 W and extruder spacer to increasing extruder tension for improved flow rate
    [Adv3 Extruder Spacer.stl, Adv3 Pi Zero mount.stl]
2024-02-27 Config update
    update printer config, add macros, include Moonraker and Fluidd configs, and add KAMP
    [Adaptive_Meshing.cfg, Adventurer-3.cfg, KAMP_Settings.cfg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]
2024-02-28 Wiring diagram scale
2024-02-28 Update printer.cfg
    Config improvements. Removed my machine's bed mesh from config.
    [printer.cfg]
2024-02-28 Add to known issues
    Adventurer 3 nozzle isn't very secure, unsure if this is an issue with my machine or all Adv3s
2024-03-01 Update README.md
    Added "clean your board" to end of part 2
2024-03-06 Updated configs
    [adv3-macros.cfg, printer.cfg]
2024-03-06 Update README.md
    Fixed stm32flash command string
2024-03-12 updated images
    prepared naming scheme for multi-printer support, added new Adventurer 3 vector art
2024-04-08 Update FUNDING.yml
    GitHub approved our application! 🥳
2024-12-05 Update Adv3 Extruder Spacer.stl
    Previous extruder spacer overcorrected the issue, causing motor skipping instead of idler slipping. This one is a much better balance, providing a modest boost in extruder tension.
    [Adv3 Extruder Spacer.stl]
2025-03-13 clarify and update compatibility
    Clarifies instructions for installing on Adventurer 3 Pro, update compat table to reflect the current status of Adventurer 5M (installer and file release pending)
2025-12-06 Fix driver model reference for Adventurer 3 Pro
2026-04-25 docs(readme): clarify main as v0.2.x manual install
    Mark main as the current manual/soldered host workflow and point users to the preview USB Install Branch for next-generation installer work.
2026-04-25 docs: update installation guide for clarity and Bookworm compatibility
    Renumber and clarify installation steps. Adjust Raspberry Pi Imager instructions and `/boot/firmware` paths for Bookworm. Update wiring, flashing parameters, and add successful flash output example. 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
